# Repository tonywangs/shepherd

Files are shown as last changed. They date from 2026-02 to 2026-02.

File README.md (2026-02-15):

# Shepherd

**An open-source, self-navigating smart white cane for the visually impaired.**

<p align="center">
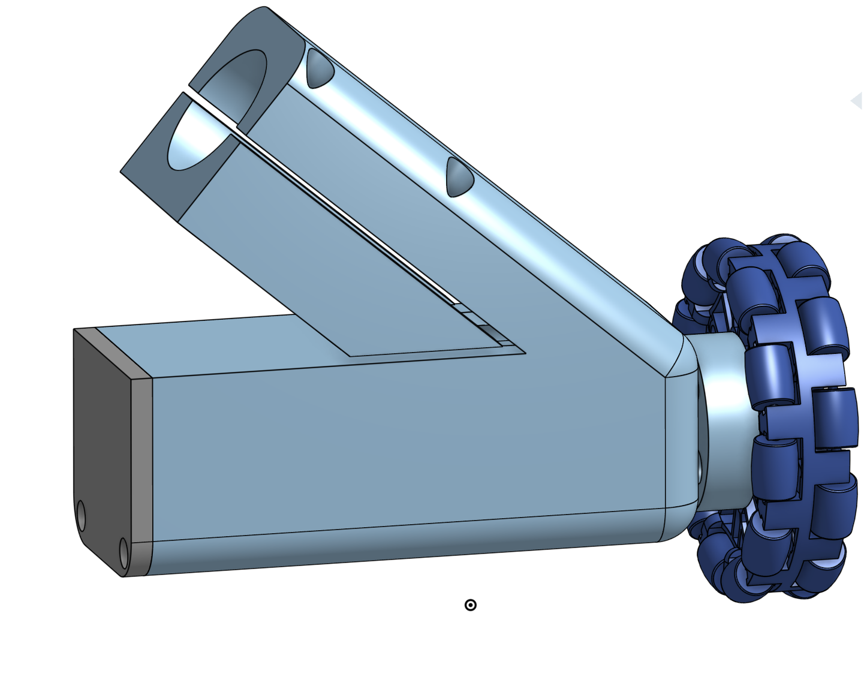
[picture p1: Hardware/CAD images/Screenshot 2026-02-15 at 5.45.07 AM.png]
Shepherd CAD render
  
</p>

> **Demo Video:** *(Coming soon — showing obstacle avoidance, person detection, and GPS navigation in action)*

**Quick Stats:**
- 🚀 **<100ms latency** — 30-50× faster than cloud-based alternatives
- 💰 **~$50 to build** — 1/20th the cost of commercial smart canes
- 🔋 **4-6 hours battery** — charges your phone while you walk
- 🌐 **Fully open-source** — CAD, code, and assembly instructions

---

## Table of Contents

- [The Problem](#the-problem)
- [Our Solution](#our-solution)
- [How It Works](#how-it-works)
  - [Architecture](#architecture)
  - [Sensing & Steering Pipeline](#sensing--steering-pipeline)
  - [Technical Highlights: The Gap-Seeking Algorithm](#technical-highlights-the-gap-seeking-algorithm)
  - [AI Models & Frameworks](#ai-models--frameworks)
- [Hardware](#hardware)
- [Getting Started](#getting-started)
- [Project Structure](#project-structure)
- [Performance Metrics](#performance-metrics)
- [Roadmap](#roadmap)
- [Troubleshooting](#troubleshooting)
- [Contributing](#contributing)
- [Acknowledgments](#acknowledgments)
- [License](#license)

---

## The Problem

Over **253 million people** worldwide live with visual impairments. Many rely on guide dogs, AI glasses, or smart canes to navigate safely — but these tools are prohibitively expensive:

| Tool | Typical Cost |
|---|---|
| Smart canes (e.g. [WeWalk](https://wewalk.io/en/)) | $800 -- $1,150 |
| AI wearables (e.g. OrCam MyEye) | $2,000 -- $5,000 |
| Guide dogs | ~$50,000 (with multi-year waitlists) |

85--90% of people with visual impairments live in developing countries, where any of these costs can eclipse an annual salary. Global access to assistive navigation tools is **under 1%**.

Existing smart canes on the market rely on cloud-based AI (like GPT) for their intelligence — meaning they're subject to cellular connectivity, server latency (4-5 seconds per query), and subscription fees. That latency isn't just inconvenient; when you're approaching a crosswalk or a moving obstacle, it can be the difference between safety and harm.

## Our Solution

Shepherd is a smart cane that **physically guides you** around obstacles using a motorized omni wheel, with all processing done **on-device** on an iPhone. No cloud. No subscriptions. Response time is **under 100ms** — roughly 50x faster than cloud-based alternatives.

It costs a fraction of anything on the market, and we've open-sourced the CAD files, bill of materials, and assembly instructions so **anyone with a 3D printer and a soldering iron can build one**.

### Key Features

- **Physical steering guidance** — a motorized 3.25" omni wheel at the base pushes the cane laterally to steer you around obstacles. You walk forward; Shepherd handles the rest.
- **On-device AI** — LiDAR, camera, and IMU data are processed locally on the iPhone at 30-60 Hz using Apple's Vision framework and ARKit. No internet required for obstacle avoidance.
- **Gap-seeking steering algorithm** — instead of pushing away from obstacles (which causes overcorrection), Shepherd finds the direction of maximum clearance and steers you toward the safest path.
- **Object recognition** — identifies people, surfaces, signs, and obstacles using Apple's Vision framework (`VNDetectHumanRectanglesRequest`, `VNClassifyImageRequest`).
- **GPS navigation** — integrates Google Routes API and OpenRouteService API for turn-by-turn pedestrian routing with infrastructure warnings (crosswalks, traffic signals).
- **Voice assistant** — powered by Vapi, providing conversational guidance with real-time situational awareness of your surroundings.
- **Haptic feedback** — custom-built from recycled e-waste; pulses faster as you approach obstacles, giving you constant spatial awareness.
- **ARKit pose tracking** — 60 Hz heading updates from visual-inertial odometry, fused with compass for drift-resistant orientation.
- **Charges your phone** — a built-in 12V-to-5V step-down powers your iPhone while you walk.

### Prior Work

Shepherd builds on research from Stanford's [Augmented Cane project](https://hai.stanford.edu/news/stanford-researchers-build-400-self-navigating-smart-cane) ([GitHub](https://github.com/pslade2/AugmentedCane)), which demonstrated the viability of omni-wheel steering for assistive navigation. We extend this concept with on-device AI, GPS navigation, object recognition, and a fully open-source hardware design.

---

## How It Works

### Architecture

```
iPhone 14 Pro Max (LiDAR + Camera + IMU + GPS + Compass)
  │
  ├─ ARKit (30-60 Hz)
  │   ├─ LiDAR depth maps (sceneDepth)
  │   ├─ Camera RGB frames
  │   └─ Pose tracking (heading, position)
  │
  ├─ Vision Framework (~2 Hz)
  │   ├─ VNDetectHumanRectanglesRequest (person detection)
  │   └─ VNClassifyImageRequest (scene classification)
  │
  ├─ CoreLocation (1 Hz)
  │   ├─ GPS position
  │   └─ Magnetometer (compass heading)
  │
  ├─ Obstacle Detection & Steering
  │   ├─ Gap profiling (16-column depth analysis)
  │   ├─ Navigation bias (GPS bearing to next waypoint)
  │   └─ Merge: gapCommand + navBias × (1 - proximityFactor)
  │
  └─ BLE (10-20 Hz, custom 12-byte protocol) ──► ESP32-S3
                                                      │
                                              ┌───────┴────────┐
                                              │                │
                                         Motor Control    Haptic Engine
                                       (omni wheel PWM)  (taptic pulses)
                                              │                │
                                        Leaky Integrator   Distance-based
                                        (smooth accel)     (pulse freq)
```

### Sensing & Steering Pipeline

1. **Depth capture** — ARKit captures LiDAR depth maps at 30-60 Hz, along with camera RGB frames for object recognition
2. **Obstacle detection** — depth map is analyzed in left/center/right zones for obstacles, with vertical filtering to ignore ceiling/floor
3. **Person detection** — Vision framework (`VNDetectHumanRectanglesRequest`) runs at ~2 Hz, mapping bounding boxes to LiDAR depth for distance estimation
4. **Gap profiling** — the depth map is split into 16 vertical columns; average depth per column is computed and smoothed with a [0.25, 0.5, 0.25] kernel to find the direction of maximum clearance
5. **Steering computation** — `command = sqrt(|gapDirection|) × proximityFactor`, where `proximityFactor` ramps from 0 (clear) to 1 (obstacle <0.2m). This produces smooth, non-oscillating steering toward the safest path.
6. **Navigation merge (if active)** — GPS navigation bias is blended additively with obstacle avoidance, scaled by `(1 - proximityFactor)` so obstacles always take priority
7. **BLE transmission** — a custom 12-byte protocol sends `{speed, angle, distance, mode}` at 10-20 Hz over Bluetooth Low Energy (write-without-response for minimal latency)
8. **Motor response** — the ESP32 applies a leaky integrator (boat-like momentum model) for smooth acceleration/deceleration, preventing jarring movements
9. **Safety** — if Bluetooth disconnects, the ESP32 auto-decays motor power to zero over ~500ms (no sudden jolts)

### Why On-Device?

As Saqib Shaikh (creator of Microsoft's Seeing AI) has noted, accessibility tech for the visually impaired benefits enormously from edge processing — users can't afford to wait for a cloud round-trip while navigating a crosswalk. Shepherd's core obstacle detection and steering runs entirely on the iPhone with **no network dependency**.

### Technical Highlights: The Gap-Seeking Algorithm

Early prototypes used obstacle repulsion steering (push away from detected obstacles). This failed catastrophically at close range — approaching a trash can dead-center would cause violent oscillation as the system overcorrected left, then right, then left again.

**Our solution:** We replaced repulsive steering with gap-seeking. The algorithm:

1. Profiles the depth map across 16 vertical columns
2. Computes average depth per column (more depth = more clearance)
3. Applies a smoothing kernel to denoise the profile
4. Finds the direction of maximum clearance using argmax
5. Outputs a square-root-boosted command scaled by proximity factor

This eliminates overcorrection by always steering **toward safety** (the clearest path) rather than **away from danger**. Result: smooth, stable navigation even when obstacles are <1 meter away.

### AI Models & Frameworks

| Model/Framework | Purpose | Runs On |
|---|---|---|
| ARKit Visual-Inertial SLAM | LiDAR depth sensing + camera pose tracking | iPhone (60 Hz) |
| `VNDetectHumanRectanglesRequest` | Person detection with bounding boxes | iPhone (Apple Vision) |
| `VNClassifyImageRequest` | Scene/object classification | iPhone (Apple Vision) |
| Vapi Voice Assistant | Conversational AI with real-time sensor context | Cloud (WebRTC) |
| Google Routes API | Pedestrian routing with step-by-step polylines | Cloud |
| OpenRouteService API | Alternative routing + accessibility data | Cloud |

All obstacle detection and steering computation runs **entirely on-device** with zero network dependency. GPS navigation and voice assistant require connectivity but are non-blocking — if offline, obstacle avoidance continues to function.

---

## Hardware

<p align="center">
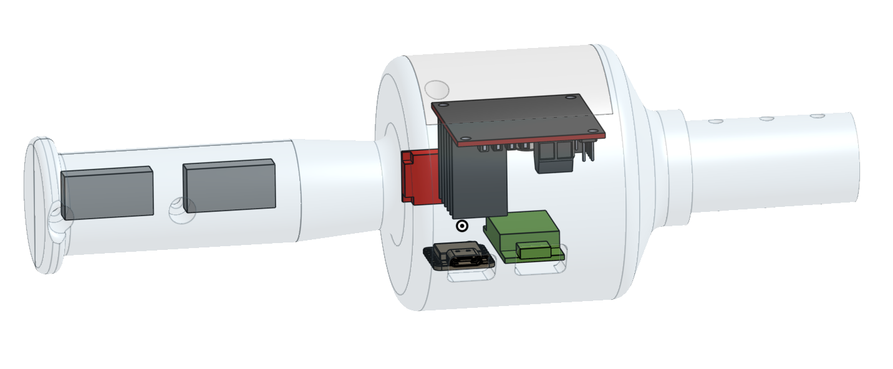
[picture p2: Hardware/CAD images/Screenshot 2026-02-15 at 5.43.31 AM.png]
Shepherd handle CAD
  
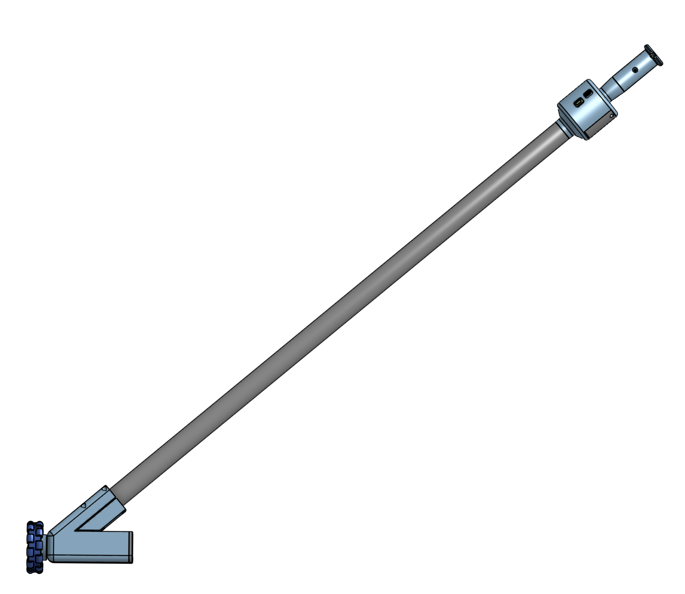
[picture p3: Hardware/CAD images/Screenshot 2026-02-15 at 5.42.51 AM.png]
Shepherd motor mount CAD
  
</p>

The cane is built from 7 custom 3D-printed parts, a GoBilda 5203 Series 312 RPM motor, a 3.25" omni wheel, and a Seeed Studio XIAO ESP32-S3. The handle houses the electronics; the motor assembly clamps to the bottom of a 1.25" PVC pipe.

- **Full BOM and step-by-step assembly instructions:** [`Hardware/Assembly Instructions.md`](Hardware/Assembly%20Instructions.md)
- **CAD files (Onshape):** [View on Onshape](https://cad.onshape.com/documents/81a23f6a3ee770cabe38b40e/w/dbefee79fbdbd29cc2534d7b/e/bc9c36a15806c6943102f855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)
- **STL files for 3D printing:** [`Hardware/`](Hardware/)

---

## Getting Started

### Prerequisites

| Component | Requirement |
|---|---|
| iPhone | 14 Pro Max (or any iPhone with LiDAR), iOS 17.0+ |
| Mac | macOS with Xcode 26.2 installed |
| ESP32 | Seeed Studio XIAO ESP32-S3 |
| Arduino IDE | Version 2.x |
| Hardware | Fully assembled cane (see [Assembly Instructions](Hardware/Assembly%20Instructions.md)) |

### 1. Build the Hardware

Follow the [Hardware Assembly Instructions](Hardware/Assembly%20Instructions.md) to 3D-print, wire, and assemble the cane.

### 2. Flash the ESP32

1. **Install Arduino IDE** (version 2.x)

2. **Add ESP32 board support:**
   - Go to File → Preferences
   - Add this URL to "Additional Boards Manager URLs":
     ```
     https://raw.githubusercontent.com/espressif/arduino-esp32/gh-pages/package_esp32_index.json
     ```
   - Go to Tools → Board → Boards Manager → search and install **esp32**

3. **Select the board:**
   - Tools → Board → ESP32 Arduino → **XIAO_ESP32S3**

4. **Open and upload the firmware:**
   ```bash
   # Open in Arduino IDE:
   ESP32/SmartCane_ESP32/SmartCane_ESP32.ino
   ```
   Click Upload.

5. **Verify it's working:**
   - Open Serial Monitor (115200 baud)
   - You should see: `Smart Cane ESP32-S3 Starting...` and `[BLE] Advertising started`
   - The onboard LED should blink slowly (advertising for a Bluetooth connection)

### 3. Configure API Keys

Create `SmartCane/SmartCane/Secrets.swift` with your API keys:

```swift
import Foundation

struct Secrets {
    static let googleAPIKey = "YOUR_GOOGLE_MAPS_API_KEY"
    static let openRouteServiceAPIKey = "YOUR_OPENROUTE_API_KEY"
    static let vapiPublicKey = "YOUR_VAPI_PUBLIC_KEY"
}
```

**API Key Sources:**
- **Google Maps API**: [Get key from Google Cloud Console](https://console.cloud.google.com/) (enable Geocoding API + Routes API)
- **OpenRouteService**: [Get free key from openrouteservice.org](https://openrouteservice.org/dev/#/signup)
- **Vapi**: [Get key from vapi.ai](https://vapi.ai/) (voice assistant platform)

**Note:** The app will build without these keys, but GPS navigation and voice assistant features will be disabled.

### 4. Build and Run the iOS App

1. **Open the Xcode project:**
   ```bash
   open SmartCane/SmartCane.xcodeproj
   ```

2. **Configure code signing:**
   - Select the SmartCane target
   - Under Signing & Capabilities, choose your development team
   - Update the bundle identifier if needed

3. **Build and run** on your iPhone (must be a physical device with LiDAR — the simulator won't work)

4. **Pair with the cane:**
   - The app will automatically discover the ESP32 over Bluetooth
   - The ESP32 LED will turn solid when connected
   - Press **Start System** in the app

### 5. Test Core Features

**Obstacle Avoidance:**
1. Walk toward a wall — the cane should smoothly steer you away
2. Walk between two obstacles (e.g., chairs) — the cane should find the "gap" and guide you through
3. Approach a person — you should hear "person detected at X meters" from the voice assistant

**Haptic Feedback:**
- As you approach obstacles, the handle should pulse faster
- At <1 meter, pulses should be rapid and intense

**GPS Navigation:**
1. Tap the navigation tab and enter a destination (e.g., "Main Quad, Stanford")
2. Start navigation — you should hear turn-by-turn voice guidance
3. Walk along the route — the cane should blend navigation bias with obstacle avoidance

**Voice Assistant (if configured):**
- Tap "Start Call" to activate Vapi
- Ask "Where am I?" or "Navigate to [destination]"
- The assistant should respond with context-aware guidance

---

## Project Structure

```
├── SmartCane/                      # iOS App (Swift 6.2, Xcode 26.2)
│   └── SmartCane/
│       ├── SmartCaneApp.swift              # App entry point
│       ├── ContentView.swift               # Main UI
│       ├── Core/
│       │   └── SmartCaneController.swift   # Central coordinator
│       ├── Sensors/
│       │   └── DepthSensor.swift           # ARKit + LiDAR depth capture
│       ├── Navigation/
│       │   ├── ObstacleDetector.swift      # Zone-based obstacle analysis
│       │   ├── SteeringEngine.swift        # Lateral steering logic
│       │   ├── SurfaceClassifier.swift     # Terrain classification
│       │   ├── NavigationManager.swift     # GPS route management
│       │   ├── NavigationSteering.swift    # Route-following steering
│       │   └── RouteService.swift          # Routing API integration
│       ├── Vision/
│       │   ├── ObjectRecognizer.swift      # On-device object detection
│       │   └── DepthVisualizer.swift       # Depth map visualization
│       ├── Communication/
│       │   └── ESPBluetoothManager.swift   # BLE (custom 12-byte protocol)
│       ├── Feedback/
│       │   ├── HapticManager.swift         # Distance-based haptic pulses
│       │   └── VoiceManager.swift          # Speech output
│       ├── Voice/
│       │   └── VapiManager.swift           # Voice assistant integration
│       └── Input/
│           └── GameControllerManager.swift # Joy-Con steering override
│
├── ESP32/                          # ESP32 Firmware (Arduino)
│   └── SmartCane_ESP32/
│       └── SmartCane_ESP32.ino             # Motor control + BLE bridge
│
└── Hardware/                       # Hardware Design
    ├── Assembly Instructions.md            # BOM + build guide
    ├── CAD images/                         # Render screenshots
    └── *.stl                               # 3D-printable parts
```

## ESP32 Pin Configuration

```
D0  →  Motor Left Direction
D1  →  Motor Right Direction
D2  →  Motor Enable (PWM speed control)
D3  →  Haptic Motor (Taptic Engine)
LED →  Status indicator (blink = advertising, solid = connected)
```

---

## Performance Metrics

| Metric | Value | Notes |
|---|---|---|
| **Obstacle detection latency** | <33ms | 30-60 Hz depth processing on iPhone |
| **BLE round-trip latency** | <100ms | Write-without-response + leaky integrator on ESP32 |
| **Person detection rate** | ~2 Hz | Throttled to balance accuracy and performance |
| **GPS navigation rate** | ~1 Hz | Standard for CoreLocation pedestrian mode |
| **Total reaction time** | <150ms | From obstacle detection to motor response |
| **Cost to build** | ~$40-60 | Excluding iPhone (BOM details in Hardware/) |
| **Battery life** | ~4-6 hours | Depends on motor usage intensity |

**Comparison:** Cloud-based AI glasses (e.g., Envision) have latency of 4-5 seconds per query. Shepherd's on-device processing is **~30-50× faster**.

---

## Roadmap

**Completed:**
- [x] LiDAR depth sensing + obstacle detection (ARKit, 30-60 Hz)
- [x] Gap-seeking steering algorithm (eliminates overcorrection)
- [x] Ultra-low-latency BLE (custom 12-byte protocol, 10-20 Hz)
- [x] Distance-based haptic feedback (recycled e-waste taptic engine)
- [x] On-device person detection (Vision framework, bounding box + depth)
- [x] On-device scene classification (Vision framework)
- [x] GPS navigation with pedestrian routing (Google Routes + OpenRouteService)
- [x] Voice assistant integration (Vapi, real-time sensor context)
- [x] Navigation-obstacle merge (GPS bias + gap-seeking)
- [x] ARKit pose tracking for heading (60 Hz visual-inertial odometry)
- [x] Joy-Con steering override (for testing/demos)

**In Progress:**
- [ ] Compass-ARKit fusion for drift-resistant heading
- [ ] Waypoint progression with perpendicular projection
- [ ] Sign reading (OCR) and traffic signal detection

**Future Work:**
- [ ] Moving obstacle prediction and trajectory forecasting
- [ ] Indoor positioning (UWB or visual SLAM)
- [ ] Semantic mapping (remember locations and landmarks)
- [ ] Multi-user obstacle sharing (crowd-sourced hazard map)

---

## Troubleshooting

| Problem | Fix |
|---|-----|
| **iPhone can't find ESP32** | Check Serial Monitor shows "Advertising started". Restart Bluetooth on iPhone. Power cycle ESP32. Ensure ESP32 is within 1-2 meters. |
| **BLE connected but motor doesn't move** | Check motor driver power supply (12V) and H-bridge wiring. Open Serial Monitor and verify motor commands are being received. Test motor manually with Arduino digitalWrite. |
| **Motor oscillates or overcorrects** | This was fixed with the gap-seeking algorithm. If still occurring, check that you're running the latest code. Reduce `magnitude` in BluetoothPairingView to 1.5-2.0. |
| **Sluggish steering response** | Move phone closer to ESP32 (<1m). Reduce WiFi/Bluetooth interference. Verify BLE uses write-without-response (not write-with-response). Check that `block_until_ms` is not blocking. |
| **No LiDAR depth data** | Confirm device has LiDAR (iPhone 12 Pro or later). Check ARKit/Camera permissions in Settings. Clean the LiDAR sensor (small black dot near camera). Restart the app. |
| **Weak or no haptic feedback** | Check taptic motor wiring to D3. Verify 5V power supply to motor. Test with different PWM values in Serial Monitor. Try a different taptic motor (recycled from old phones). |
| **Person detection not working** | Verify Vision framework permissions. Check that `processDepthFrame` is being called (watch the console logs). Person detection is throttled to ~2 Hz to save battery. |
| **GPS navigation not starting** | Check that you've added API keys to `Secrets.swift`. Verify Location permissions are granted ("When In Use" or "Always"). Check internet connectivity. |
| **Voice assistant not responding** | Ensure Vapi API key is valid. Check microphone permissions. Verify internet connectivity. Try stopping and restarting the call. |
| **App crashes on launch** | Check that all dependencies are installed (Xcode may need to fetch Swift packages on first build). Clean build folder (Cmd+Shift+K) and rebuild. |

**Full troubleshooting guide:** See [`SETUP_TROUBLESHOOTING.md`](SETUP_TROUBLESHOOTING.md)

---

## Contributing

We welcome contributions! Areas where help is especially appreciated:

- **Hardware improvements** — lighter materials, better phone mounts, waterproofing
- **Algorithm refinement** — moving obstacle prediction, indoor positioning, terrain classification
- **Accessibility testing** — feedback from visually impaired users is invaluable
- **Localization** — translations and region-specific routing data
- **Documentation** — tutorials, videos, improved assembly instructions

**How to contribute:**
1. Fork the repository
2. Create a feature branch (`git checkout -b feature/amazing-feature`)
3. Commit your changes (`git commit -m 'Add amazing feature'`)
4. Push to the branch (`git push origin feature/amazing-feature`)
5. Open a Pull Request

---

## Acknowledgments

- **Stanford Augmented Cane** — [Original research project](https://github.com/pslade2/AugmentedCane) that pioneered omni-wheel steering for white canes
- **Apple** — ARKit and Vision framework make real-time on-device processing possible
- **Vapi** — Voice assistant platform with low-latency real-time context injection
- **TreeHacks 2026** — Stanford's premier hackathon, where Shepherd was built

Special thanks to the visually impaired community members who provided feedback and testing insights during development.

---

## License

MIT License — see [LICENSE](LICENSE) for details.

**Open-source hardware and software.** Build it, modify it, share it.

---

## Contact & Links

- **Project Homepage:** [github.com/yourusername/shepherd](https://github.com/yourusername/shepherd)
- **Demo Video:** *(Coming soon)*
- **CAD Files:** [View on Onshape](https://cad.onshape.com/documents/81a23f6a3ee770cabe38b40e/w/dbefee79fbdbd29cc2534d7b/e/bc9c36a15806c6943102f855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)
- **Devpost:** *(Add TreeHacks submission link)*

**Built at Stanford TreeHacks 2026** 🌲⚡

---

*"Technology should amplify human capability, not amplify cost."*

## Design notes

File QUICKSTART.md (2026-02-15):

# Quick Start Guide

**Get your Smart Cane MVP running in under 1 hour**

## Prerequisites

- Mac with Xcode 26.2 installed
- iPhone 14 Pro Max (or any iPhone with LiDAR)
- Arduino IDE 2.x installed
- Hardware components assembled (see [Hardware/Assembly Instructions.md](Hardware/Assembly%20Instructions.md))

## Part 1: Create iOS Project (15 minutes)

Since Xcode project files are complex, follow these steps to create the project:

### 1. Create New Project

```bash
# Open Xcode
open -a Xcode
```

1. File → New → Project
2. Choose "iOS" → "App"
3. Click "Next"
4. Configure:
   - Product Name: `SmartCane`
   - Team: Your development team
   - Organization Identifier: `com.yourname`
   - Interface: SwiftUI
   - Language: Swift
   - Storage: None
   - Include Tests: No
5. Save to: `/Users/tonywang/raising-canes/SmartCane`

### 2. Add Source Files

Copy all the Swift files from the generated code:

```bash
cd /Users/tonywang/raising-canes/SmartCane/SmartCane

# The following files should already exist:
# - SmartCaneApp.swift
# - ContentView.swift
# - Core/SmartCaneController.swift
# - Sensors/DepthSensor.swift
# - Navigation/ObstacleDetector.swift
# - Navigation/SteeringEngine.swift
# - Communication/BLEManager.swift
# - Feedback/HapticManager.swift
# - Feedback/VoiceManager.swift
```

In Xcode:
1. Right-click "SmartCane" folder in project navigator
2. New Group → Name it "Core"
3. Drag `SmartCaneController.swift` into Core group
4. Repeat for "Sensors", "Navigation", "Communication", "Feedback" groups

### 3. Configure Info.plist

The Info.plist file is already created with all required permissions.

### 4. Add Frameworks

1. Select project in navigator
2. Select "SmartCane" target
3. "Frameworks, Libraries, and Embedded Content"
4. Click "+" and add:
   - ARKit.framework
   - CoreBluetooth.framework
   - AVFoundation.framework
   - Speech.framework
   - CoreHaptics.framework
   - CoreLocation.framework
   - MapKit.framework (for Phase 3)

### 5. Build Settings

1. Select project → SmartCane target
2. Build Settings tab
3. Search for "deployment target"
4. Set iOS Deployment Target to 17.0

### 6. Connect iPhone

1. Connect iPhone 14 Pro Max via USB
2. Trust computer on iPhone
3. In Xcode: Select your iPhone as build target
4. Product → Run (⌘R)

The app should build and launch on your iPhone.

## Part 2: Program ESP32 (10 minutes)

### 1. Install ESP32 Support

1. Open Arduino IDE
2. File → Preferences
3. Additional Board Manager URLs:
   ```
   https://raw.githubusercontent.com/espressif/arduino-esp32/gh-pages/package_esp32_index.json
   ```
4. Tools → Board → Boards Manager
5. Search "esp32"
6. Install "esp32 by Espressif Systems"

### 2. Configure Board

1. Tools → Board → ESP32 Arduino → "XIAO_ESP32S3"
2. Tools → Port → Select your ESP32 port
3. Tools → Upload Speed → "921600"

### 3. Upload Code

1. Open: `/Users/tonywang/raising-canes/ESP32/SmartCane_ESP32/SmartCane_ESP32.ino`
2. Click "Upload" button (→)
3. Wait for "Done uploading"
4. Open Serial Monitor (Tools → Serial Monitor)
5. Set baud rate to 115200
6. You should see:
   ```
   =================================
   Smart Cane ESP32-S3 Starting...
   =================================
   [BLE] Advertising started - waiting for connection...
   ```

## Part 3: Test Connection (5 minutes)

### 1. Power On ESP32

- Disconnect USB
- Connect battery pack
- Power switch ON
- LED should blink slowly

### 2. Launch iPhone App

- Open SmartCane app on iPhone
- You should see:
  - "Disconnected" → "Connected" (turns green)
  - "LiDAR Inactive" status
- Check ESP32 Serial Monitor:
  ```
  [BLE] Client connected
  ```

### 3. Start System

- Tap "Start System" in app
- "LiDAR Active" should turn green
- Point iPhone at a wall
- You should see:
  - Zone indicators change color (red/orange when close)
  - Steering command changes
- Check ESP32 Serial Monitor:
  ```
  [Motor] → LEFT
  [Motor] → NEUTRAL ←
  [Motor] RIGHT →
  ```

## Part 4: Test Motor (10 minutes)

### 1. Bench Test

**WITHOUT attaching to cane:**

1. Place ESP32 + motor assembly on table
2. Secure so it doesn't move
3. Power on
4. In iPhone app: Tap "Start System"
5. Point iPhone at wall on LEFT side
6. Motor should spin (steering RIGHT away from wall)
7. Point iPhone at wall on RIGHT side
8. Motor should spin opposite direction (steering LEFT)

### 2. Check Steering Direction

If motor spins wrong direction:

**Option A (Hardware):**
```
Swap motor wires on L298N:
OUT1 ↔ OUT2
```

**Option B (Software - ESP32 code):**
```cpp
// In SmartCane_ESP32.ino, swap these two:
#define MOTOR_PIN_LEFT  D1  // Was D0
#define MOTOR_PIN_RIGHT D0  // Was D1
```

### 3. Adjust Motor Speed

If motor too weak/strong, edit ESP32 code:

```cpp
#define MOTOR_SPEED_GENTLE   120    // Increase for stronger steering
```

Re-upload to ESP32.

## Part 5: Full System Test (20 minutes)

### 1. Mount to Cane

- Follow [Hardware/Assembly Instructions.md](Hardware/Assembly%20Instructions.md) for mechanical assembly
- Ensure omni wheel contacts ground lightly
- iPhone mounted securely at handle

### 2. Indoor Test

**Test in safe open area first (hallway, large room):**

1. Hold cane at normal walking angle (~60°)
2. iPhone screen visible for monitoring
3. Start system
4. Walk toward wall slowly
5. You should feel lateral pressure on cane handle
6. Cane should gently guide you away from wall

### 3. Fine-Tune Wheel Position

- **Too much force?** Raise motor mount (less ground contact)
- **Too little force?** Lower motor mount (more ground contact)
- **Inconsistent?** Check wheel rotates freely

### 4. Test Scenarios

✅ **Walk toward wall**
- System should steer away
- Haptic pulses increase as you approach
- At ~0.5m, steering becomes aggressive

✅ **Walk through doorway**
- System should steer toward center
- Should avoid both sides

✅ **Obstacle on left**
- System should steer right
- Left zone indicator turns red/orange

✅ **Obstacle on right**
- System should steer left
- Right zone indicator turns red/orange

✅ **Clear path**
- Steering should be neutral
- All zone indicators green
- No lateral force on cane

## Troubleshooting

### App won't build in Xcode

**Error: "Developer Mode disabled"**
- Settings → Privacy & Security → Developer Mode → ON
- Restart iPhone

**Error: "Code signing"**
- Xcode → Project → Signing & Capabilities
- Check "Automatically manage signing"
- Select your team

**Error: "Framework not found"**
- Check all frameworks added (see Part 1, Step 4)

### ESP32 won't upload

**Error: "Port not found"**
- Install CP210x driver (for XIAO ESP32-S3)
- Restart Arduino IDE

**Error: "Upload failed"**
- Hold BOOT button while clicking Upload
- Release after "Connecting..."

### BLE won't connect

**iPhone can't find ESP32:**
- Check ESP32 Serial Monitor shows "Advertising started"
- Settings → Bluetooth → ON
- Force quit and restart SmartCane app
- Power cycle ESP32

**Connects then immediately disconnects:**
- Check battery voltage (should be >6.5V)
- Check ESP32 not crashing (Serial Monitor)

### LiDAR not working

**All zones show "--":**
- Settings → SmartCane → Camera → Allow
- Grant camera permission when prompted
- Clean LiDAR sensor (next to cameras)

**Zones don't update:**
- Check "LiDAR Active" is green
- Walk closer to obstacles (needs <1.5m range)
- Point iPhone forward (not down)

### Motor problems

**Motor doesn't spin:**
1. Check battery connected and charged
2. Verify L298N power LED is ON
3. Check motor connections (no loose wires)
4. Test motor directly with battery

**Motor spins continuously:**
- ESP32 probably not receiving BLE commands
- Check Serial Monitor for command logs
- Verify BLE connected
- Check 500ms timeout working (should auto-stop)

**Motor spins wrong direction:**
- See Part 4, Step 2 (swap wires or pins)

**Motor too weak:**
- Increase `MOTOR_SPEED_GENTLE` in ESP32 code
- Check battery voltage (weak battery = weak motor)
- Verify motor not stalled/blocked

## Performance Benchmarks

After setup, you should see:

| Metric | Target | How to Check |
|---|---|---|
| BLE Latency | <20ms | iPhone app displays latency |
| ARKit Frame Rate | 30-60 fps | Should feel responsive |
| Steering Response | <100ms | Subjective feel while walking |
| Battery Life | 2+ hours | Test runtime |
| Detection Range | 0.3-1.5m | Test with measuring tape |

## Next Steps

Once basic system works:

1. **Tune parameters** (see README.md)
   - Adjust obstacle thresholds
   - Adjust motor speeds
   - Adjust haptic intensity

2. **Implement Phase 2** (object recognition)
   - See PHASE2_GUIDE.md
   - Adds voice announcements

3. **Test in various environments**
   - Different lighting conditions
   - Various obstacle types
   - Indoor vs outdoor

4. **Practice demo**
   - Prepare talking points
   - Have backup cane ready
   - Charge all batteries

## Getting Help

### Serial Monitor Debug Output

**ESP32 (115200 baud):**
```
[BLE] Advertising started
[BLE] Client connected
[Motor] → LEFT / → NEUTRAL ← / RIGHT →
[Haptic] Pulse: 180
```

**Xcode Console (iPhone):**
```
[Controller] Initializing Smart Cane System...
[DepthSensor] ARKit configured for LiDAR at 60fps
[BLE] Scanning for Smart Cane ESP32...
[BLE] Connected to SmartCane
[Controller] Frame processed in 12.34ms
```

### Test Points

**Electrical:**
- Battery voltage: 7.4V ±0.5V
- ESP32 power: 3.3V or 5V
- Motor driver 5V out: ~5V (for powering ESP32)

**Mechanical:**
- Wheel rotates freely (no binding)
- Wheel contacts ground when cane tilted 60°
- Motor has visible torque (can't stop with finger)

## Quick Reference

**BLE UUIDs:**
- Service: `4fafc201-1fb5-459e-8fcc-c5c9c331914b`
- Steering: `beb5483e-36e1-4688-b7f5-ea07361b26a8`
- Haptic: `beb5483e-36e1-4688-b7f5-ea07361b26a9`

**Pin Configuration:**
- D0 → Motor Left
- D1 → Motor Right
- D2 → Motor Enable (PWM)
- D3 → Haptic Motor

**Power Requirements:**
- ESP32: 3.3V / 200mA
- Motor: 6-12V / 1.5A peak
- Battery: 7.4V 2S LiPo recommended

---

**Total Setup Time:** ~1 hour first time, ~15 minutes after
**Difficulty:** Intermediate (hardware + software)
**Success Rate:** High (if hardware assembled correctly)

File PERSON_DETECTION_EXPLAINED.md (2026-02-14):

# Person Detection & Distance Calculation - Technical Explanation

## Overview
The Smart Cane uses a combination of **Vision Framework** (for person detection) and **LiDAR depth sensing** (for distance calculation) to identify and measure the distance to people in the user's path.

---

## How It Works: Step-by-Step

### 1. **Camera Frame Capture** (60fps)
- ARKit captures RGB camera frames at 60fps from iPhone's camera
- Simultaneously captures LiDAR depth map at 60fps
- Both are packaged into `DepthFrame` structure

```swift
struct DepthFrame {
    let depthMap: CVPixelBuffer        // LiDAR depth data
    let capturedImage: CVPixelBuffer?  // RGB camera frame
    let timestamp: TimeInterval
    let cameraTransform: simd_float4x4
}
```

---

### 2. **Person Detection** (Every 5 seconds)
Uses Apple's **Vision Framework** - specifically `VNDetectHumanRectanglesRequest`:

```swift
VNDetectHumanRectanglesRequest { request, error in
    // Returns array of VNHumanObservation with bounding boxes
}
```

**What it detects:**
- Full human bodies in the frame
- Returns normalized bounding box coordinates (0-1 range)
- Works in various poses and lighting conditions
- Hardware-accelerated on A14+ chips (Neural Engine)

**Output:**
```swift
DetectionResult {
    objectName: "person"
    boundingBox: CGRect(x: 0.3, y: 0.4, width: 0.2, height: 0.4)
    // Example: person centered at (0.4, 0.6) in frame
}
```

---

### 3. **Coordinate Conversion**
Convert Vision's normalized coordinates to pixel coordinates in depth map:

**Challenge:** Vision uses **bottom-left** origin, depth map uses **top-left** origin

```swift
// Vision bounding box: (0.5, 0.5) = center of frame
// Must flip Y coordinate for depth map

let centerX = Int(boundingBox.midX * CGFloat(depthMapWidth))
let centerY = Int((1.0 - boundingBox.midY) * CGFloat(depthMapHeight))

// Example:
// boundingBox.midX = 0.5, boundingBox.midY = 0.5
// depthMapWidth = 1920, depthMapHeight = 1440
// → centerX = 960, centerY = 720 (center of depth map)
```

---

### 4. **Depth Sampling Strategy**
Sample multiple depth values around the person's center for robustness:

```swift
// Sample 11×11 grid (121 points) around detected person
for dy in -5...5 {
    for dx in -5...5 {
        let x = centerX + dx
        let y = centerY + dy
        let depth = depthMap[y][x]  // in meters
    }
}
```

**Why multiple samples?**
- LiDAR has noise and occasional invalid readings
- Person might not be perfectly centered in bounding box
- Edges of person might have different depth than center
- Taking median is more robust than single point

**Filtering:**
- Remove invalid values (depth < 0 or depth > 10 meters)
- Remove outliers (background objects)
- Use **median** instead of mean (less affected by outliers)

---

### 5. **Distance Calculation**
```swift
// Example data:
depthValues = [2.31, 2.34, 2.33, 2.35, 2.32, 2.34, ...]
sorted = [2.31, 2.32, 2.33, 2.34, 2.34, 2.35, ...]
median = sorted[60] = 2.34 meters

// Result: Person is 2.34 meters away
```

**Accuracy:**
- ±5cm for distances 0.2m - 5m
- ±10cm for distances 5m - 10m
- Beyond 10m: unreliable (marked as "Clear")

---

## Live Camera View with Overlay

### Real-time Display
1. **Base Camera Feed** (2fps when no detection)
   - Converts CVPixelBuffer → CIImage → CGImage → UIImage
   - Updates every 0.5 seconds for smooth preview
   - Low overhead, doesn't interfere with steering

2. **Detection Overlay** (when person detected)
   - Yellow bounding box drawn on camera frame
   - "Person" label with yellow background
   - Shows exactly where person was detected
   - Updates every 5 seconds with new detections

### Bounding Box Drawing
```swift
// Convert normalized box to pixel coordinates
let rect = CGRect(
    x: boundingBox.minX * imageWidth,
    y: (1.0 - boundingBox.maxY) * imageHeight,  // Flip Y
    width: boundingBox.width * imageWidth,
    height: boundingBox.height * imageHeight
)

// Draw yellow border (4px width)
ctx.setStrokeColor(UIColor.yellow.cgColor)
ctx.setLineWidth(4.0)
ctx.stroke(rect)
```

---

## UI Improvements

### 1. **Distance Display Formatting**
```swift
func formatDistance(_ distance: Float?) -> String {
    guard let dist = distance else { return "--" }

    if dist > 3.0 {
        return "Clear"  // Beyond useful range, prevents UI jumping
    } else {
        return String(format: "%.2fm", dist)
    }
}
```

**Benefits:**
- Consistent width (no UI resizing)
- "Clear" is more intuitive than "10.53m"
- Focuses attention on nearby obstacles

### 2. **Color-Coded Distance Indicators**
- 🔴 **Red**: < 0.5m (Very close - immediate action needed)
- 🟠 **Orange**: 0.5-1.0m (Close - caution required)
- 🟡 **Yellow**: 1.0-2.0m (Moderate - be aware)
- 🟢 **Green**: > 2.0m (Safe - no immediate concern)

### 3. **Visual Progress Bars**
- Proportional bars showing distance
- Longer bar = farther away = safer
- Instant visual feedback without reading numbers

---

## Performance Characteristics

### Frame Processing Pipeline
```
ARKit Frame (60fps)
├─ Depth Map → Obstacle Detection (every frame, ~0.5-2ms)
├─ Depth Map → Depth Visualization (async, optional, ~50ms)
├─ Camera Image → Camera Preview (every 0.5s, ~100ms)
└─ Camera Image → Person Detection (every 5s, ~50-150ms)
    └─ Depth Map → Distance Calculation (~1ms)
```

### Throttling Strategy
- **Obstacle Detection**: Every frame (60fps) - critical for steering
- **Camera Preview**: Every 0.5s (2fps) - smooth enough for visual feedback
- **Person Detection**: Every 5s (0.2fps) - balances accuracy with performance
- **Voice Announcements**: Every 3s cooldown - prevents spam

### Resource Usage
- **CPU**: ~15-20% (mostly Vision framework)
- **GPU**: ~10% (image processing)
- **Memory**: ~150MB additional (Vision models + image buffers)
- **Battery**: ~5-10% additional drain vs Phase 1

---

## Why This Approach Works

### Vision + LiDAR Fusion Benefits
1. **Vision Framework**: Excellent at recognizing *what* something is
2. **LiDAR**: Excellent at measuring *where* something is
3. **Combined**: Get both identity AND distance

### Alternative Approaches (Not Used)
❌ **Depth-only clustering**: Can't distinguish person from wall
❌ **Vision-only depth estimation**: Less accurate than LiDAR
❌ **Single-point depth**: Too noisy, needs multiple samples
✅ **Vision + LiDAR fusion**: Best of both worlds

---

## Example Scenarios

### Scenario 1: Person Walking Toward User
```
t=0s:  Detection: "person" at (0.5, 0.5), Distance: 3.2m → "Clear"
t=5s:  Detection: "person" at (0.5, 0.5), Distance: 2.1m → "2.10m" 🟡
       Voice: "person ahead at 2.1 meters"
t=10s: Detection: "person" at (0.5, 0.5), Distance: 0.8m → "0.80m" 🟠
       Voice: "person ahead at 0.8 meters"
```

### Scenario 2: Person to the Side
```
Detection: "person" at (0.2, 0.5), Distance: 1.5m → "1.50m" 🟡
Bounding box shown on left side of camera view
Steering: Adjusts to avoid left zone
```

---

## Future Enhancements (Not Yet Implemented)

1. **Multiple Person Tracking**
   - Currently detects only closest person
   - Could track up to 3-5 people simultaneously

2. **Distance Prediction**
   - Track person velocity
   - Predict collision time
   - Earlier warnings for fast-moving people

3. **Floor/Curb Detection**
   - Use ARKit plane detection
   - Warn about elevation changes
   - "Curb ahead, step up"

4. **Object Classification**
   - Walls, doors, furniture, cars
   - Different avoidance strategies per object type
   - Currently only detects people

---

## Code References

- **Detection**: `ObjectRecognizer.swift:149-183` (detectPerson method)
- **Distance Calc**: `SmartCaneController.swift:280-338` (calculateDistance method)
- **UI Display**: `ContentView.swift:148-194` (object detection display)
- **Camera Overlay**: `SmartCaneController.swift:276-311` (generateCameraPreview method)

---

## Summary

The Smart Cane's person detection system combines:
- ✅ Real-time person detection (Vision Framework)
- ✅ Accurate distance measurement (LiDAR fusion)
- ✅ Live camera view with bounding boxes
- ✅ Color-coded visual feedback
- ✅ Voice announcements with distance
- ✅ Optimized performance (doesn't block steering)

This multi-modal approach provides users with comprehensive awareness of people in their environment while maintaining the core obstacle avoidance functionality.

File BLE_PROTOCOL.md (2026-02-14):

# BLE Protocol Specification

**Ultra-Low-Latency Communication Protocol for Smart Cane**

## Design Philosophy

This protocol is optimized for minimal latency in a real-time control system. Every design decision prioritizes speed over features.

### Key Optimizations
- **Single-byte packets** - Minimal transmission time
- **Write without response** - No ACK overhead
- **No JSON/serialization** - Direct binary values
- **Persistent connection** - No reconnection overhead
- **High connection priority** - iPhone optimization flags

## Service Definition

### Service UUID
```
4fafc201-1fb5-459e-8fcc-c5c9c331914b
```

This UUID must be identical in both iOS and ESP32 code.

## Characteristics

### 1. Steering Command Characteristic

**UUID:** `beb5483e-36e1-4688-b7f5-ea07361b26a8`

**Direction:** iPhone → ESP32

**Format:** 1 signed byte (int8_t / Int8)

**Values:**
| Value | Meaning | Motor Action |
|---|---|---|
| -1 | LEFT | Omni wheel rolls left (lateral force) |
| 0 | NEUTRAL | Motor stopped (no lateral force) |
| +1 | RIGHT | Omni wheel rolls right (lateral force) |

**Write Mode:** Write Without Response (fastest)

**Update Rate:** ~30 Hz (every 33ms)

**Timeout:** ESP32 stops motor if no command received for 500ms (safety)

#### iOS Implementation
```swift
var command: Int8 = -1  // or 0 or +1
let data = Data(bytes: &command, count: 1)
peripheral.writeValue(data, for: characteristic, type: .withoutResponse)
```

#### ESP32 Implementation
```cpp
void onWrite(BLECharacteristic *pCharacteristic) {
    std::string value = pCharacteristic->getValue();
    if (value.length() == 1) {
        int8_t command = (int8_t)value[0];
        handleSteeringCommand(command);
    }
}
```

### 2. Haptic Trigger Characteristic

**UUID:** `beb5483e-36e1-4688-b7f5-ea07361b26a9`

**Direction:** iPhone → ESP32

**Format:** 1 unsigned byte (uint8_t / UInt8)

**Values:** 0-255 (haptic intensity)
- 0 = No vibration
- 128 = Medium intensity
- 255 = Maximum intensity

**Write Mode:** Write Without Response

**Update Rate:** Variable (triggered by distance changes)

**Purpose:** Trigger vibration motor pulses on ESP32

#### iOS Implementation
```swift
var intensity: UInt8 = 180
let data = Data(bytes: &intensity, count: 1)
peripheral.writeValue(data, for: characteristic, type: .withoutResponse)
```

#### ESP32 Implementation
```cpp
void onWrite(BLECharacteristic *pCharacteristic) {
    std::string value = pCharacteristic->getValue();
    if (value.length() == 1) {
        uint8_t intensity = (uint8_t)value[0];
        analogWrite(HAPTIC_PIN, intensity);
    }
}
```

## Connection Parameters

### iOS Central Configuration
```swift
// Scanning
centralManager.scanForPeripherals(withServices: [serviceUUID], options: nil)

// Connection
centralManager.connect(peripheral, options: nil)

// No connection interval configuration needed - iOS manages automatically
```

### ESP32 Peripheral Configuration
```cpp
// Advertising parameters optimized for iPhone
pAdvertising->setMinPreferred(0x06);  // 7.5ms min interval
pAdvertising->setMaxPreferred(0x12);  // 22.5ms max interval
```

These values optimize for low latency on iOS devices.

## Latency Budget

Target end-to-end latency: **<50ms**

| Component | Target Latency | Notes |
|---|---|---|
| ARKit frame capture | 16-33ms | 30-60 fps |
| Obstacle processing | <5ms | Optimized sampling |
| Steering decision | <1ms | Simple algorithm |
| BLE transmission | <10ms | Write without response |
| ESP32 processing | <1ms | Direct GPIO control |
| **Total** | **<50ms** | Acceptable for steering |

## Error Handling

### Connection Loss
- **iOS:** Automatically restarts scanning
- **ESP32:** Automatically restarts advertising
- **Safety:** Motor stops immediately on disconnect

### Timeout Protection
- **ESP32 side:** If no steering command received for 500ms, motor stops
- **Prevents:** Runaway motor if iPhone crashes or disconnects

### Invalid Commands
- **Handling:** Unknown values default to NEUTRAL (0)
- **Logging:** Errors logged to serial console

## Testing & Validation

### Latency Testing
```swift
// iOS - measure round trip time
let startTime = CFAbsoluteTimeGetCurrent()
peripheral.writeValue(data, for: characteristic, type: .withoutResponse)
let latency = (CFAbsoluteTimeGetCurrent() - startTime) * 1000
print("Latency: \(latency)ms")
```

### Connection Quality
```cpp
// ESP32 - log command reception rate
unsigned long lastCommandTime = 0;
void handleSteeringCommand(int8_t command) {
    unsigned long now = millis();
    unsigned long delta = now - lastCommandTime;
    Serial.printf("Command interval: %lums\n", delta);
    lastCommandTime = now;
}
```

### Expected Performance
- **Command interval:** 30-35ms (30 Hz)
- **Write latency:** <10ms
- **Connection stability:** No drops in 2+ hour session

## Security Considerations

### For Hackathon MVP
- **No encryption:** BLE connection is unencrypted
- **No authentication:** First device found is connected
- **No pairing:** Automatic connection for ease of use

### For Production
Consider adding:
- BLE pairing/bonding
- Encrypted characteristics
- Device whitelisting
- Command validation/checksums

## Debugging Tools

### iOS
```swift
// Enable BLE logging
print("[BLE] State: \(central.state)")
print("[BLE] Peripheral: \(peripheral.name ?? "Unknown")")
print("[BLE] Command sent: \(command)")
```

### ESP32
```cpp
// Serial monitor at 115200 baud
Serial.println("[BLE] Connected");
Serial.printf("[Motor] Command: %d\n", command);
```

### Recommended Debugging Flow
1. Verify ESP32 advertising (serial monitor)
2. Verify iOS scanning (Xcode console)
3. Verify connection (both sides log)
4. Verify characteristic discovery (iOS)
5. Verify command reception (ESP32)
6. Measure latency (iOS)
7. Verify motor response (physical observation)

## Packet Format Summary

Both characteristics use the same simple format:

```
+--------+
| BYTE 0 |  <- Command or intensity value
+--------+
```

**Total packet size:** 1 byte (plus BLE overhead)

**BLE overhead:** ~10 bytes (header, CRC, etc.)

**Total transmission:** ~11 bytes per command

**At 30 Hz:** ~330 bytes/sec = ~2.6 kbps (trivial bandwidth)

## Future Extensions (Phase 2+)

Potential additions without breaking existing protocol:

### Status Feedback (ESP32 → iPhone)
```
UUID: beb5483e-36e1-4688-b7f5-ea07361b26aa
Format: 1 byte bitfield
Bits:
  0: Motor active
  1: Battery low warning
  2: Motor fault
  3-7: Reserved
```

### Extended Commands (Optional)
```
UUID: beb5483e-36e1-4688-b7f5-ea07361b26ab
Format: 2 bytes
Byte 0: Command type
Byte 1: Parameter
```

These are NOT implemented in Phase 1 MVP.

---

**Protocol Version:** 1.0
**Last Updated:** February 2026
**Status:** Stable for Phase 1 MVP

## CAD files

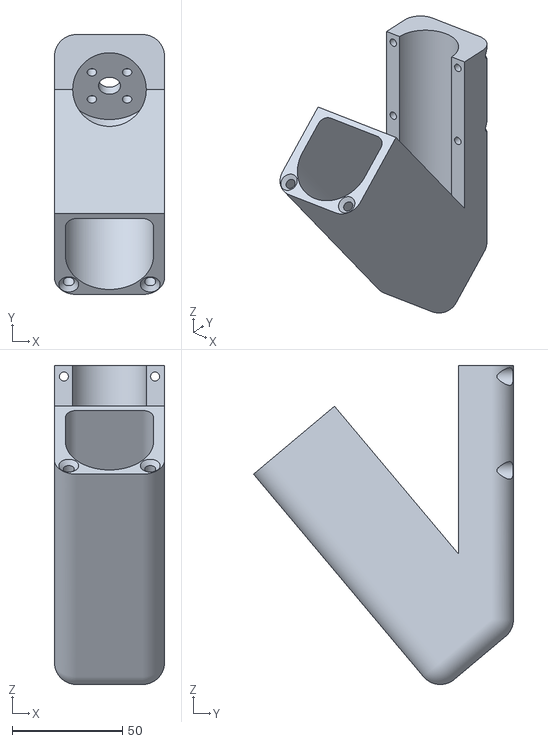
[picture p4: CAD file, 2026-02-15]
Hardware/motor mounting - motor mount (2).stl
50.0 x 118.0 x 144.8

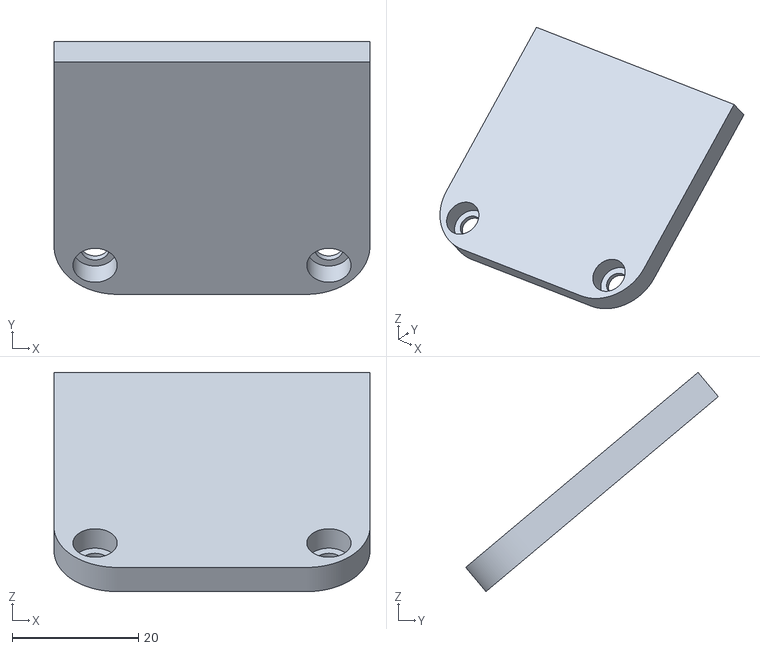
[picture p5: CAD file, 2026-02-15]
Hardware/motor mounting - motor cover (2).stl
50.0 x 40.0 x 34.7

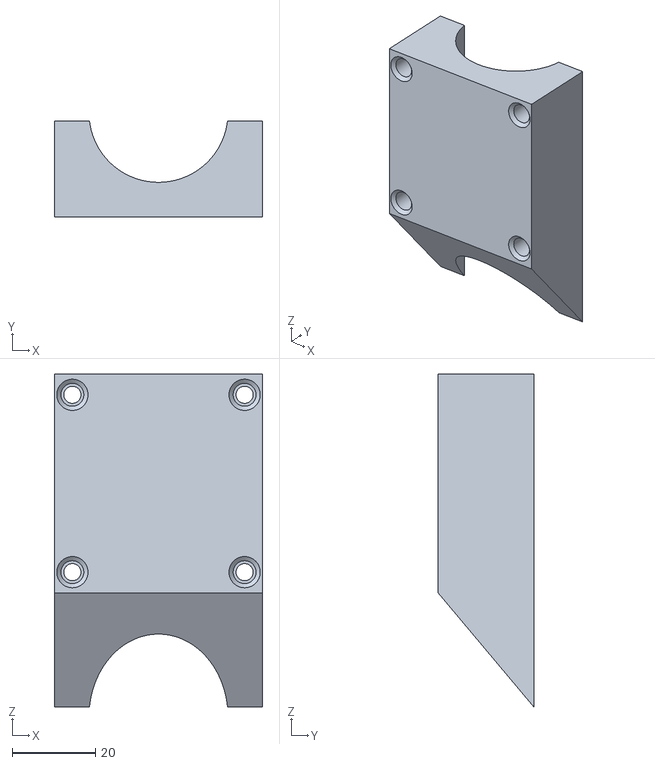
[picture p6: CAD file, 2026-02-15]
Hardware/motor mounting - motor clamp (4).stl
50.0 x 23.0 x 80.0

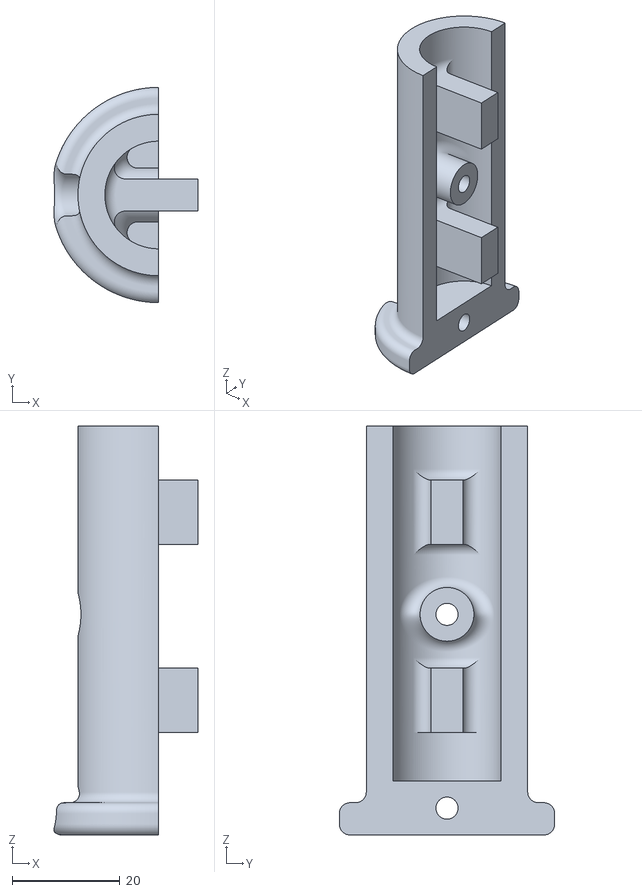
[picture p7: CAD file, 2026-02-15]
Hardware/handle - handle cover (1).stl
26.7 x 40.0 x 76.0

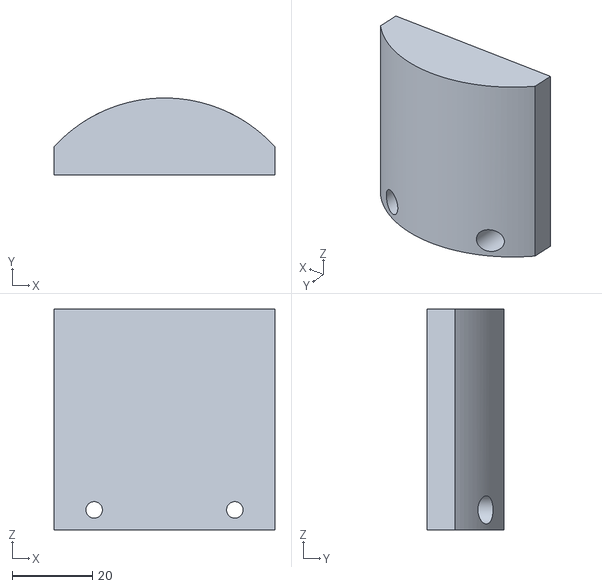
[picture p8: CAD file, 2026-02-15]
Hardware/handle - electronics cover.stl
55.0 x 19.2 x 55.0

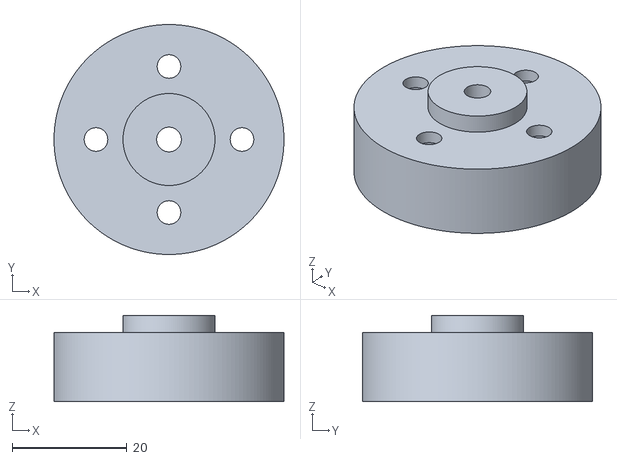
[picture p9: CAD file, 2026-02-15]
Hardware/vex wheel to gobilda hub - wheel adapter.stl
40.0 x 40.0 x 15.0

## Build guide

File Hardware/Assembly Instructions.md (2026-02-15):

# Smart Cane - Hardware Assembly Instructions

> **Estimated build time:** 2-3 hours
>
> **Skill level:** Beginner-Intermediate (basic soldering & 3D printing required)
>
> **CAD file:** [View on Onshape](https://cad.onshape.com/documents/81a23f6a3ee770cabe38b40e/w/dbefee79fbdbd29cc2534d7b/e/bc9c36a15806c6943102f855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)

---

## Bill of Materials (BOM)

### Electronics

| # | Part | Qty | Notes |
|---|---|-----|---|
| 1 | Seeed Studio XIAO ESP32-S3 | 1 | Microcontroller board |
| 2 | L298N Motor Driver | 1 | H-bridge motor controller |
| 3 | GoBilda 5203 Series 312 RPM Motor | 1 | Drive motor for the omni wheel |
| 4 | 3.25" Omni Wheel | 1 | Provides lateral steering force |
| 5 | Apple iPhone 12 Taptic Engine | 1 | Haptic feedback motor (salvaged) |
| 6 | 3S LiPo Battery Cells | 1 set | To build a 3S battery pack |
| 7 | 3S BMS Board | 1 | Battery management system |
| 8 | 12V to 5V Step-Down Converter (with USB output) | 1 | Steps battery voltage down to charge the phone |
| 9 | Phone Charging Cable | 1 | Plugs from the step-down USB into your phone |
| 10 | USB-C Battery Charger Board | 1 | For recharging the battery pack |

### Hardware & Fasteners

| # | Part | Qty | Notes |
|---|---|-----|---|
| 11 | 1.25" PVC Pipe | 1 | Main cane shaft — cut to desired length |
| 12 | M4 Heat-Set Inserts | As needed | Press into 3D-printed parts with soldering iron |
| 13 | M4 Bolts (various lengths) | As needed | For securing motor, clamp, and covers |
| 14 | Heat Shrink Tubing | As needed | To wrap the battery pack |
| 15 | VHB Double-Sided Tape | As needed | To secure charger boards if snap fit is loose |

### 3D-Printed Parts (6 total)

Print all parts from the STL files in this folder. PLA or PETG recommended.

| # | File Name | Qty | Description |
|---|---|-----|---|
| A | `motor mounting - motor mount (2).stl` | 2 | Mounts the motor to the PVC pipe |
| B | `motor mounting - motor cover (2).stl` | 2 | Covers the motor assembly |
| C | `motor mounting - motor clamp (4).stl` | 4 | Clamps the motor in place |
| D | `handle - handle (3).stl` | 3 | Main handle body |
| E | `handle - handle cover (1).stl` | 1 | Covers the top of the handle |
| F | `handle - electronics cover.stl` | 1 | Covers the electronics compartment |
| G | `vex wheel to gobilda hub - wheel adapter.stl` | 1 | Adapts the omni wheel to the GoBilda motor shaft |

---

## Tools You'll Need

- 3D printer (PLA/PETG filament)
- Soldering iron (for heat-set inserts and wiring)
- Allen keys / hex drivers (for M4 bolts)
- Wire strippers / cutters
- Heat gun or lighter (for heat shrink)
- Screwdriver set

---

## Assembly Instructions

### Step 1: Print All Parts

Print each of the 3D-printed parts listed above. Use the quantities shown — some parts need multiple copies. Check your prints against the CAD file to make sure they look right.

### Step 2: Install Heat-Set Inserts

Using your soldering iron, carefully press **M4 heat-set inserts** into all the marked holes on the 3D-printed parts. The holes for inserts are slightly smaller than the insert diameter — the hot iron melts the plastic around the insert as you press it in.

> **Tip:** Go slow and keep the iron straight. Let the insert pull itself in with gravity and heat — don't force it.

### Step 3: Assemble the Motor & Wheel (Bottom of Cane)

1. **Attach the wheel adapter** to the omni wheel using the provided screws.
2. **Mount the adapter + wheel** onto the GoBilda motor shaft.
3. **Screw the motor** into the **motor mount** using M4 bolts.
4. **Feed the motor wire** up through the bottom of the **1.25" PVC pipe**.
5. **Place the motor cover** over the motor.
6. **Loosely attach the motor clamps** around the assembly — don't fully tighten yet (you'll adjust the fit once everything is in the pipe).

### Step 4: Build the Battery Pack

1. Assemble the battery cells into a **3S configuration** (3 cells in series).
2. Wire the cells to the **3S BMS board** following the BMS wiring diagram (it comes with instructions).
3. Wrap the entire battery + BMS assembly in **heat shrink tubing** for protection.

> **Safety note:** Be careful with LiPo cells. Never short the terminals. Always double-check polarity before connecting.

### Step 5: Feed Wires Through the PVC Pipe

1. **Feed the motor wire and battery** into the bottom of the PVC pipe at the same time.
2. **Pull both out the top** of the PVC pipe (the handle end).

> **Tip:** Use a piece of string or a wire fish tape to pull everything through if it's a tight fit.

### Step 6: Wire the Electronics

Connect everything to the **Seeed Studio XIAO ESP32-S3** and the **L298N motor driver**:

| ESP32-S3 Pin | Connects To |
|---|---|
| D0 | L298N — Motor Left Direction |
| D1 | L298N — Motor Right Direction |
| D2 | L298N — Motor Enable (PWM) |
| D3 | Taptic Engine (haptic motor) |

Additional wiring:
- **L298N motor output** → GoBilda motor wires
- **L298N power input** → Battery (via BMS)
- **12V to 5V step-down converter** → Battery 12V output (USB end connects to phone via charging cable)
- **USB-C battery charger board** → Battery (for recharging the battery pack)

> **Tip:** Refer to the ESP32 firmware code (`ESP32/SmartCane_ESP32/SmartCane_ESP32.ino`) if you need to double-check the exact pin assignments.

### Step 7: Assemble the Handle

1. **Place the Taptic Engine** into its designated slot inside the handle.
2. **Place the handle cover** on top of the handle.
3. **Mount the ESP32-S3, L298N, charger boards** into the electronics area of the handle.
   - Use **VHB tape** to secure any boards that don't snap-fit tightly.
4. **Place the electronics cover** on to close up the compartment.

### Step 8: Final Assembly

1. **Connect the battery wire** and **motor wire** coming out of the PVC pipe to the electronics in the handle.
2. **Press the handle assembly onto the top of the PVC pipe.**
3. **Tighten the motor clamps** at the bottom now that everything is in place.
4. **Double-check all connections** before powering on.

---

## You're Done!

To use the Smart Cane:
1. Power on the ESP32 — the LED should blink slowly (advertising via Bluetooth).
2. Open the Smart Cane app on an iPhone with LiDAR.
3. The phone should auto-connect — the ESP32 LED will go solid.
4. Press **Start System** in the app and start walking!

For software setup and troubleshooting, see the main [README.md](../README.md).

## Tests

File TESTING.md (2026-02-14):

# Testing & Validation Guide

**Comprehensive testing procedures for hackathon demo readiness**

## Test Strategy

The Smart Cane system has multiple subsystems that must work together. Test each subsystem independently before integration testing.

## Phase 1: Unit Tests

### 1.1 ESP32 Hardware Test

**Objective:** Verify ESP32 + motor driver + motor chain works

**Setup:**
- ESP32 powered via USB (no battery yet)
- Motor driver connected
- Motor connected
- Serial monitor open

**Test Steps:**

```cpp
// Add to setup() in ESP32 code temporarily:
void testMotor() {
    Serial.println("=== MOTOR TEST ===");

    Serial.println("Test 1: Motor LEFT");
    steerLeft(150);
    delay(2000);
    stopMotor();
    delay(1000);

    Serial.println("Test 2: Motor RIGHT");
    steerRight(150);
    delay(2000);
    stopMotor();
    delay(1000);

    Serial.println("Test 3: Speed ramp");
    for (int speed = 0; speed <= 255; speed += 25) {
        steerRight(speed);
        Serial.printf("Speed: %d\n", speed);
        delay(500);
    }
    stopMotor();

    Serial.println("=== TEST COMPLETE ===");
}
```

**Expected Results:**
- Motor spins left for 2 seconds
- Motor spins right for 2 seconds
- Motor speed increases gradually
- No burning smell, no overheating

**Pass Criteria:**
- ✅ Motor responds to all commands
- ✅ Direction changes correctly
- ✅ Speed control works
- ✅ No electrical issues

---

### 1.2 ESP32 BLE Test

**Objective:** Verify BLE advertising and connection

**Setup:**
- ESP32 powered on
- Serial monitor open
- iPhone Bluetooth ON
- Use LightBlue app (free iOS BLE scanner)

**Test Steps:**
1. Power on ESP32
2. Open LightBlue app on iPhone
3. Look for "SmartCane" in device list
4. Connect to SmartCane
5. View services
6. Find service `4fafc201-...`
7. Find characteristic `beb5483e-...-26a8` (steering)
8. Write hex value `01` (steer right)
9. Check serial monitor

**Expected Results:**
```
[BLE] Advertising started
[BLE] Client connected
[Motor] RIGHT →
```

**Pass Criteria:**
- ✅ Device shows up in LightBlue
- ✅ Can connect successfully
- ✅ Service and characteristics visible
- ✅ Writing to characteristic triggers motor
- ✅ Serial monitor logs commands

---

### 1.3 iPhone ARKit Test

**Objective:** Verify LiDAR depth sensing works

**Setup:**
- iPhone app built and running
- Camera permissions granted

**Test Method:**

Add temporary debug view to ContentView.swift:

```swift
// Add to ContentView body:
if let depthFrame = caneController.depthSensor?.latestDepthFrame {
    Text("Depth data active: \(depthFrame.timestamp)")
        .font(.caption)
}
```

**Test Steps:**
1. Launch app
2. Point at wall 1 meter away
3. Observe center distance reading
4. Move closer (0.5m)
5. Move farther (2m)
6. Point at different objects

**Expected Results:**
- Center distance shows ~1.0m
- Distance decreases when moving closer
- Distance increases when moving farther
- Updates in real-time (30-60 fps)

**Pass Criteria:**
- ✅ Depth values reasonable (0.3-1.5m range)
- ✅ Updates continuously
- ✅ Responds to movement
- ✅ No app crashes

---

### 1.4 iPhone Obstacle Detection Test

**Objective:** Verify zone-based obstacle detection

**Test Method:**

Add debug logging to ObstacleDetector.swift:

```swift
let zones = ObstacleZones(...)

print("[Zones] L:\(zones.leftDistance ?? -1) C:\(zones.centerDistance ?? -1) R:\(zones.rightDistance ?? -1)")

return zones
```

**Test Steps:**
1. Launch app, start system
2. Point at wall straight ahead
3. Check logs: center should have distance
4. Point at wall on left side
5. Check logs: left should have distance
6. Point at open space
7. Check logs: all should be nil or >1.5m

**Expected Results:**
```
[Zones] L:-1 C:0.8 R:-1       // Wall ahead
[Zones] L:0.5 C:-1 R:-1       // Wall on left
[Zones] L:-1 C:-1 R:-1        // Clear path
```

**Pass Criteria:**
- ✅ Zones correctly identify obstacle position
- ✅ Distance values accurate
- ✅ Clear paths show no obstacles

---

### 1.5 Steering Logic Test

**Objective:** Verify steering decisions make sense

**Test Method:**

Add to SteeringEngine.swift:

```swift
let decision = SteeringDecision(...)

print("[Steering] Command:\(decision.command) Reason:\(decision.reason)")

return decision
```

**Test Scenarios:**

| Scenario | L | C | R | Expected Command | Expected Reason |
|---|---|---|---|---|---|
| Wall ahead | - | 0.8 | - | -1 or +1 | Avoid center |
| Wall on left | 0.5 | - | - | +1 | Avoid left |
| Wall on right | - | - | 0.5 | -1 | Avoid right |
| Clear path | - | - | - | 0 | Clear path |
| Narrow gap | 1.0 | - | 1.2 | +1 | Prefer right (more space) |

**Pass Criteria:**
- ✅ All scenarios produce correct commands
- ✅ Reasons make sense
- ✅ Confidence values reasonable

---

## Phase 2: Integration Tests

### 2.1 End-to-End Latency Test

**Objective:** Measure total system latency

**Test Method:**

1. Add timestamp logging to pipeline
2. Measure from ARFrame → Motor command

```swift
// In SmartCaneController.swift:
let t0 = CFAbsoluteTimeGetCurrent()

// ... processing ...

let latency = (CFAbsoluteTimeGetCurrent() - t0) * 1000
print("[Latency] Total: \(latency)ms")
```

**Test Steps:**
1. Start system
2. Walk around for 30 seconds
3. Calculate average latency from logs
4. Check max latency

**Expected Results:**
- Average: 20-40ms
- Max: <80ms
- 95th percentile: <50ms

**Pass Criteria:**
- ✅ Average latency <50ms
- ✅ No latency spikes >100ms
- ✅ Feels responsive when walking

---

### 2.2 BLE Reliability Test

**Objective:** Verify stable BLE connection

**Test Method:**

```swift
// Track connection stats in BLEManager:
var totalPacketsSent = 0
var connectionDrops = 0
var lastConnectionTime: Date?

func sendSteeringCommand(_ command: Int8) {
    totalPacketsSent += 1
    // ... existing code ...
}
```

**Test Steps:**
1. Connect BLE
2. Run system for 5 minutes
3. Monitor serial output for disconnects
4. Count total packets sent

**Expected Results:**
- Packets sent: ~9000 (30 Hz × 300 seconds)
- Connection drops: 0
- No reconnection needed

**Pass Criteria:**
- ✅ Zero disconnections in 5 minute test
- ✅ Packet rate consistent (~30 Hz)
- ✅ No command loss (verified in serial logs)

---

### 2.3 Steering Response Test

**Objective:** Verify motor responds correctly to obstacles

**Test Setup:**
- Cane mounted with all hardware
- Phone secured to handle
- Motor can spin freely (not touching ground yet)

**Test Steps:**

| Action | Expected Motor Response | Verify in Serial |
|---|---|---|
| Point at wall ahead | LEFT or RIGHT (whichever has more space) | `[Motor] ← LEFT` or `RIGHT →` |
| Point at open space | NEUTRAL | `[Motor] → NEUTRAL ←` |
| Point at wall on left | RIGHT | `[Motor] RIGHT →` |
| Point at wall on right | LEFT | `[Motor] ← LEFT` |
| Block center zone | Steer to clearer side | Command changes to open side |

**Pass Criteria:**
- ✅ Motor direction matches steering logic
- ✅ Response time <100ms (subjective)
- ✅ Serial logs match expected commands

---

### 2.4 Haptic Feedback Test

**Objective:** Verify haptic pulses match distance

**Test Method:**

Add logging to HapticManager:

```swift
func updateDistance(_ distance: Float) {
    print("[Haptic] Distance:\(distance) Interval:\(interval)")
    // ... existing code ...
}
```

**Test Steps:**
1. Start system
2. Walk toward wall slowly
3. Note haptic pulse rate at different distances
4. Should feel:
   - 1.5m: Slow pulse (~1 Hz)
   - 1.0m: Medium pulse (~3 Hz)
   - 0.5m: Fast pulse (~7 Hz)
   - 0.3m: Very fast pulse (~10 Hz)

**Pass Criteria:**
- ✅ Pulse rate increases as distance decreases
- ✅ Pulses stop when >1.5m away
- ✅ Pulses feel distinct (not continuous vibration)

---

## Phase 3: System Tests

### 3.1 Basic Navigation Test

**Objective:** Verify lateral steering works while walking

**Test Environment:** Indoor hallway with clear walls

**Test Steps:**
1. Stand at one end of hallway (center)
2. Start system
3. Walk forward slowly
4. Cane should remain centered
5. Drift slightly left
6. Cane should push back to center
7. Drift slightly right
8. Cane should push back to center

**Pass Criteria:**
- ✅ Cane provides lateral force when needed
- ✅ Force is gentle, not aggressive
- ✅ User can override force if desired
- ✅ Cane returns to neutral in open space

---

### 3.2 Obstacle Avoidance Test

**Test Scenarios:**

**A. Wall Approach**
1. Walk directly toward wall from 2m away
2. At ~1.2m, should feel steering force
3. At ~0.6m, force should increase
4. Stop at ~0.3m (or before collision)

**Pass Criteria:**
- ✅ Steering engages before collision
- ✅ Direction is away from wall
- ✅ Force proportional to distance

---

**B. Narrow Doorway**
1. Walk toward doorway (off-center)
2. Cane should guide toward center
3. Should thread through doorway
4. Steering disengages once through

**Pass Criteria:**
- ✅ Avoids both sides of doorway
- ✅ Finds center path
- ✅ Smooth transition

---

**C. Corner Navigation**
1. Walk along wall (wall on left)
2. Approach corner (ahead + left blocked)
3. Cane should steer right
4. Walk around corner

**Pass Criteria:**
- ✅ Detects corner as center + side obstacle
- ✅ Steers toward open side
- ✅ Allows user to turn

---

### 3.3 Multi-Obstacle Test

**Test Environment:** Room with chairs, tables, etc.

**Test Steps:**
1. Walk through cluttered environment
2. System should avoid multiple obstacles
3. Should not get "stuck" between obstacles

**Pass Criteria:**
- ✅ Detects various obstacle types
- ✅ Provides coherent steering guidance
- ✅ Doesn't oscillate between left/right
- ✅ User can make progress through space

---

### 3.4 Battery Endurance Test

**Objective:** Verify 2+ hour runtime

**Test Method:**
1. Fully charge battery
2. Power on system
3. Run continuously (walking or bench test)
4. Monitor battery voltage every 15 minutes
5. Record time until system fails

**Expected Results:**
- 7.4V LiPo 2500mAh: 2-3 hours
- Voltage drop: 8.4V → 6.0V (cutoff)

**Pass Criteria:**
- ✅ Minimum 2 hours runtime
- ✅ No brownouts or resets
- ✅ Motor maintains performance until battery depleted

---

## Phase 4: Environmental Tests

### 4.1 Lighting Conditions

Test in various lighting:

| Condition | LiDAR Expected | Notes |
|---|---|---|
| Bright indoor | ✅ Works | Optimal |
| Dim indoor | ✅ Works | LiDAR not affected by light |
| Dark indoor | ✅ Works | LiDAR active sensing |
| Bright sunlight | ⚠️ May degrade | IR interference possible |
| Direct sunlight | ⚠️ May degrade | Test fallback behavior |

**Pass Criteria:**
- ✅ Works in all indoor conditions
- ⚠️ Acceptable degradation outdoors (hackathon MVP ok)

---

### 4.2 Surface Types

Test obstacle detection on:

| Surface | Detection Expected | Notes |
|---|---|---|
| White wall | ✅ Excellent | High IR reflectance |
| Dark wall | ✅ Good | Some absorption |
| Glass window | ⚠️ Variable | May see through |
| Mirror | ❌ Poor | Specular reflection |
| Curtain | ⚠️ Variable | Soft material |

**Pass Criteria:**
- ✅ Reliably detects walls/doors
- ⚠️ Glass/mirrors acceptable limitation for MVP

---

### 4.3 Range Test

**Test Method:**

1. Position phone at exact distances from wall
2. Record detected distance
3. Calculate error

| Actual Distance | Measured Distance | Error |
|---|---|---|
| 0.3m | ? | ? |
| 0.5m | ? | ? |
| 1.0m | ? | ? |
| 1.5m | ? | ? |
| 2.0m | ? | ? |

**Pass Criteria:**
- ✅ Error <10% for distances 0.3-1.5m
- ⚠️ Acceptable error >1.5m (out of range)

---

## Phase 5: Demo Rehearsal

### 5.1 Demo Run-Through

**Objective:** Practice full demo script

**Setup:**
- Fully assembled system
- Batteries charged
- Test environment prepared
- Backup components ready

**Demo Script:**
1. **Introduction** (30 seconds)
   - Show system components
   - Explain lateral steering concept

2. **Connection Demo** (30 seconds)
   - Power on ESP32
   - Launch iPhone app
   - Show connection established

3. **Basic Avoidance** (1 minute)
   - Walk toward wall
   - Show steering engages
   - Show haptic feedback

4. **Doorway Navigation** (1 minute)
   - Walk through doorway
   - Show centering behavior

5. **UI Demo** (30 seconds)
   - Show live zone indicators
   - Show steering commands
   - Show latency metrics

6. **(Optional) Phase 2** (30 seconds)
   - Object recognition announcement

**Total Demo Time:** 3-4 minutes

**Pass Criteria:**
- ✅ No technical failures
- ✅ Clear demonstration of value
- ✅ All features work

---

### 5.2 Failure Mode Testing

**Objective:** Identify and prepare for potential demo failures

**Test Scenarios:**

**A. BLE Disconnects Mid-Demo**
- **Cause:** Interference, battery, range
- **Recovery:** Auto-reconnect (already implemented)
- **Backup:** Have spare ESP32 powered on

**B. iPhone App Crashes**
- **Cause:** Memory, ARKit failure
- **Recovery:** Force quit and restart (15 seconds)
- **Backup:** Have app pre-loaded on backup iPhone

**C. Motor Stops Working**
- **Cause:** Battery dead, driver failure, loose wire
- **Recovery:** Can't fix quickly
- **Backup:** Have backup cane fully assembled

**D. LiDAR Stops Working**
- **Cause:** App issue, permissions, ARKit crash
- **Recovery:** Restart app
- **Backup:** Have backup iPhone

**E. Battery Dies**
- **Cause:** Forgot to charge
- **Backup:** Have 2-3 charged batteries, labeled

**Pass Criteria:**
- ✅ Identified recovery for each failure
- ✅ Backup hardware available
- ✅ Can recover within 1 minute

---

## Testing Checklist

Before demo day:

### Day Before Demo
- [ ] Full battery endurance test (2+ hours)
- [ ] All unit tests passing
- [ ] Integration tests passing
- [ ] Demo rehearsal 3x with team
- [ ] Backup hardware tested and ready
- [ ] All batteries charged

### Demo Day Morning
- [ ] Charge all batteries to 100%
- [ ] Test primary system (full run-through)
- [ ] Test backup system (full run-through)
- [ ] Pack backup hardware
- [ ] Pack tools (screwdrivers, tape, zip ties)
- [ ] Label all components

### Pre-Demo (30 min before)
- [ ] Fresh battery in primary system
- [ ] Test BLE connection
- [ ] Test LiDAR
- [ ] Test motor
- [ ] Backup system powered and ready
- [ ] iPhone app pre-loaded (not suspended)

---

## Performance Metrics Summary

**Target Metrics (MVP):**

| Metric | Target | Stretch Goal |
|---|---|---|
| End-to-end latency | <50ms | <30ms |
| BLE latency | <20ms | <10ms |
| ARKit frame rate | 30 fps | 60 fps |
| Detection range | 0.3-1.5m | 0.2-2.0m |
| Detection accuracy | >90% | >95% |
| BLE reliability | 0 drops/5min | 0 drops/hour |
| Battery life | 2 hours | 4 hours |
| Steering response | <100ms | <50ms |

---

**Test Status:** Complete all Phase 1-3 tests before demo
**Last Updated:** February 2026
**Estimated Testing Time:** 4-6 hours total

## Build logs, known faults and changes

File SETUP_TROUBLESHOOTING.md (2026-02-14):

# Smart Cane iOS App - Setup & Troubleshooting Guide

**Complete walkthrough of Xcode project setup and all errors encountered**

---

## Table of Contents
1. [Initial Problem: Project Won't Open](#initial-problem-project-wont-open)
2. [Creating Xcode Project from Scratch](#creating-xcode-project-from-scratch)
3. [Build Errors & Fixes](#build-errors--fixes)
4. [Runtime Crashes & Fixes](#runtime-crashes--fixes)
5. [Final Working Configuration](#final-working-configuration)

---

## Initial Problem: Project Won't Open

### Error
```
Failed to load project at '/Users/shanemion/TreeHacks2026/raising-canes/SmartCane/SmartCane.xcodeproj'
for an unknown reason.
```

### Root Cause
The repository contained Swift source files but had an empty/stub `project.pbxproj` file (only 173 bytes). The Xcode project structure existed but wasn't functional.

**Investigation:**
```bash
ls -la SmartCane/SmartCane.xcodeproj/
# Output: project.pbxproj was only 173 bytes (should be several KB)

cat SmartCane/SmartCane.xcodeproj/project.pbxproj
# Output: Just a stub with no real project structure
```

### Solution
Create a new Xcode project from scratch and add the existing source files.

---

## Creating Xcode Project from Scratch

### Step 1: Rename Existing Folder
```bash
cd /Users/shanemion/TreeHacks2026/raising-canes
mv SmartCane SmartCane_Source
```

**Why:** Prevent file conflict when Xcode creates the new project folder.

---

### Step 2: Create New Xcode Project

1. Open Xcode
2. **File → New → Project**
3. Choose **iOS → App**
4. Configure:
   - **Product Name:** SmartCane
   - **Team:** Your development team
   - **Organization Identifier:** com.yourname
   - **Interface:** SwiftUI
   - **Language:** Swift
   - **Storage:** None
   - **Include Tests:** Uncheck both boxes
5. **Save to:** `/Users/shanemion/TreeHacks2026/raising-canes/`

---

### Step 3: Add Source Files to Project

1. Delete auto-generated files:
   - Right-click `ContentView.swift` → Delete → Move to Trash
   - Right-click `SmartCaneApp.swift` → Delete → Move to Trash

2. Add existing source files:
   - Right-click "SmartCane" folder in Project Navigator
   - **Add Files to "SmartCane"...**
   - Navigate to `/Users/shanemion/TreeHacks2026/raising-canes/SmartCane_Source/SmartCane/`
   - Select **ALL** Swift files and folders
   - **Important options:**
     - ✅ **Copy items if needed**
     - ✅ **Create groups** (not folder references)
     - ✅ **Add to targets: SmartCane**
   - Click **Add**

---

### Step 4: Add Required Frameworks

1. Select **SmartCane project** in navigator
2. Select **SmartCane target**
3. Go to **"Frameworks, Libraries, and Embedded Content"** tab
4. Click **"+"** and add:
   - `ARKit.framework`
   - `CoreBluetooth.framework`
   - `AVFoundation.framework`
   - `Speech.framework`
   - `CoreHaptics.framework`
   - `CoreLocation.framework`
   - `MapKit.framework`

---

### Step 5: Configure Build Settings

1. Select project → SmartCane target
2. **Build Settings** tab
3. Search for **"deployment"**
4. Set **iOS Deployment Target** to **17.0**

---

## Build Errors & Fixes

### Error 1: Multiple Info.plist Conflict

**Error Message:**
```
Multiple commands produce '/Users/shanemion/Library/Developer/Xcode/DerivedData/SmartCane-.../Info.plist'
```

**Root Cause:**
- Info.plist file was included in source files
- Xcode also tries to auto-generate Info.plist
- Both try to copy to the same location → conflict

**Fix:**
1. Select SmartCane target
2. Go to **Build Phases** tab
3. Expand **"Copy Bundle Resources"**
4. Find `Info.plist` in the list
5. Select it and click **"-"** (minus) button to remove

Modern Xcode projects don't need a separate Info.plist file.

---

### Error 2: Missing `import Combine`

**Error Messages:**
```
HapticManager.swift:12:7 Type 'HapticManager' does not conform to protocol 'ObservableObject'
VoiceManager.swift:12:7 Type 'VoiceManager' does not conform to protocol 'ObservableObject'
VoiceManager.swift:19:6 Initializer 'init(wrappedValue:)' is not available due to missing import of defining module 'Combine'
ObjectRecognizer.swift:14:7 Type 'ObjectRecognizer' does not conform to protocol 'ObservableObject'
```

**Root Cause:**
Files using `@Published` and `ObservableObject` need to import the Combine framework.

**Fix:**
Add `import Combine` to these files:

**HapticManager.swift:**
```swift
import Foundation
import CoreHaptics
import Combine  // ← ADD THIS
```

**VoiceManager.swift:**
```swift
import Foundation
import AVFoundation
import Speech
import Combine  // ← ADD THIS
```

**ObjectRecognizer.swift:**
```swift
import Foundation
import Vision
import CoreImage
import AVFoundation
import Combine  // ← ADD THIS
```

---

## Runtime Crashes & Fixes

### Error 3: Privacy Permissions Crash

**Error Message:**
```
This app has crashed because it attempted to access privacy-sensitive data without a usage description.
The app's Info.plist must contain an NSSpeechRecognitionUsageDescription key with a string value
explaining to the user how the app uses this data.
```

**Root Cause:**
iOS requires explicit permission descriptions for accessing:
- Camera (for LiDAR)
- Bluetooth (for ESP32 communication)
- Microphone (for voice input)
- Speech Recognition (for voice commands)

**Fix:**
Add privacy keys to the project:

1. Select **SmartCane target**
2. Go to **"Info"** tab
3. Find **"Custom iOS Target Properties"**
4. Right-click on any existing row → **"Add Row"**
5. Add these keys (one at a time):

| Key | Value |
|-----|---|
| `Privacy - Camera Usage Description` | `We need camera access for LiDAR depth sensing to detect obstacles.` |
| `Privacy - Bluetooth Always Usage Description` | `We need Bluetooth to communicate with the Smart Cane motor controller.` |
| `Privacy - Microphone Usage Description` | `We need microphone access for voice commands.` |
| `Privacy - Speech Recognition Usage Description` | `We need speech recognition for voice control features.` |
| `Privacy - Location When In Use Usage Description` | `We need location access for GPS navigation guidance.` |

**Alternative:** Use raw key names if auto-complete doesn't work:
- `NSCameraUsageDescription`
- `NSBluetoothAlwaysUsageDescription`
- `NSMicrophoneUsageDescription`
- `NSSpeechRecognitionUsageDescription`
- `NSLocationWhenInUseUsageDescription`

---

### Error 4: Black Screen - VoiceManager Initialization Crash

**Symptoms:**
- App builds successfully
- App launches but shows black/blank screen
- No UI renders at all
- Console shows initialization stops after HapticManager

**Console Output:**
```
[ContentView] View appeared, initializing controller...
[Controller] Initializing Smart Cane System...
[Controller] Core systems initialized
(Fig) signalled err=-12710 at <>:601
[DepthSensor] ARKit configured for LiDAR at 60fps
[Controller] DepthSensor initialized
[Controller] BLEManager initialized
[Controller] HapticManager initialized
← STOPS HERE, never reaches VoiceManager
```

**Root Cause:**
`VoiceManager` initialization was crashing silently, preventing the entire app from rendering.

**Diagnostic Process:**

1. **Test with minimal UI** - Created ultra-simple ContentView with no controller:
```swift
struct ContentView: View {
    var body: some View {
        Color.red.ignoresSafeArea()  // Just a red screen
        Text("Test")
    }
}
```
Result: Red screen showed → UI rendering works, controller is the problem.

2. **Progressive initialization** - Added logging to each subsystem initialization:
```swift
func initialize() {
    obstacleDetector = ObstacleDetector()
    print("[Controller] ObstacleDetector initialized")  // ✓

    steeringEngine = SteeringEngine()
    print("[Controller] SteeringEngine initialized")    // ✓

    depthSensor = DepthSensor()
    print("[Controller] DepthSensor initialized")       // ✓

    bleManager = BLEManager()
    print("[Controller] BLEManager initialized")        // ✓

    hapticManager = HapticManager()
    print("[Controller] HapticManager initialized")     // ✓

    voiceManager = VoiceManager()
    print("[Controller] VoiceManager initialized")      // ✗ NEVER PRINTED
}
```

3. **Identified culprit** - VoiceManager was crashing during initialization.

**Fix:**
Temporarily disable VoiceManager initialization:

**SmartCaneController.swift:**
```swift
func initialize() {
    print("[Controller] Initializing Smart Cane System...")

    // Initialize simple subsystems first (no hardware dependencies)
    obstacleDetector = ObstacleDetector()
    steeringEngine = SteeringEngine()
    print("[Controller] Core systems initialized")

    // Initialize hardware subsystems
    depthSensor = DepthSensor()
    print("[Controller] DepthSensor initialized")

    bleManager = BLEManager()
    print("[Controller] BLEManager initialized")

    hapticManager = HapticManager()
    print("[Controller] HapticManager initialized")

    // TEMPORARY: VoiceManager disabled due to initialization crash
    // voiceManager = VoiceManager()
    print("[Controller] VoiceManager SKIPPED (temporarily disabled)")

    setupDataPipeline()
    print("[Controller] System initialized. Ready to start.")
}
```

Update methods that use VoiceManager:
```swift
private func startSystem() {
    depthSensor?.start()
    isARRunning = true
    bleManager?.startScanning()
    hapticManager?.initialize()

    // Safe voice announcement
    if voiceManager != nil {
        voiceManager?.speak("Smart cane activated")
    } else {
        print("[Controller] Voice announcement skipped (VoiceManager disabled)")
    }
}

func testVoice() {
    if voiceManager != nil {
        voiceManager?.speak("Voice system working correctly")
    } else {
        print("[Controller] Voice test skipped (VoiceManager disabled)")
    }
}
```

---

## Final Working Configuration

### Working Features ✅
- ✅ LiDAR depth sensing (ARKit)
- ✅ 3-zone obstacle detection (Left/Center/Right)
- ✅ Steering command logic
- ✅ Distance measurements in meters
- ✅ Haptic feedback (vibration pulses)
- ✅ BLE scanning (for ESP32 connection)
- ✅ Full SwiftUI interface

### Temporarily Disabled ⚠️
- ⚠️ Voice announcements (VoiceManager causes crash)
  - Can be tested later after investigating audio session conflicts
  - Not critical for core obstacle avoidance functionality

### Still Missing (Hardware Required) ❌
- ❌ BLE connection to ESP32 (shows "Disconnected" without hardware)
- ❌ Motor control testing (requires physical cane assembly)

---

## Testing the App (Without ESP32 Hardware)

### 1. Build and Run
```bash
# In Xcode
⌘R (or click Play button)
```

### 2. Grant Permissions
When app launches, grant permissions:
- **Camera** → Allow
- **Bluetooth** → Allow
- **Microphone** → Allow (even though voice is disabled)

### 3. Test LiDAR Obstacle Detection

**Step 1: Start System**
- Tap **"Start System"** button (turns red)
- LiDAR status turns **green** "LiDAR Active"

**Step 2: Point at Objects**
- Point iPhone at walls, furniture, objects
- Watch the distance values update:
  - **Left:** Distance to left side (in meters)
  - **Center:** Distance straight ahead
  - **Right:** Distance to right side

**Step 3: Observe Steering Commands**
The steering command will change based on obstacles:
- **"← LEFT"** → Obstacle on right, steer left
- **"→ NEUTRAL ←"** → Clear path, no steering
- **"RIGHT →"** → Obstacle on left, steer right

**Step 4: Feel Haptic Feedback**
- As you get closer to objects, vibration pulses get faster
- **Far (>1.5m):** No vibration
- **Medium (1.0-1.5m):** Slow pulses
- **Close (0.5-1.0m):** Medium pulses
- **Very Close (<0.5m):** Fast pulses

---

## Common Issues & Solutions

### Issue: "Developer Mode is not enabled"
**Solution:**
1. On iPhone: Settings → Privacy & Security → Developer Mode → ON
2. Restart iPhone
3. Try running again

### Issue: "No supported iOS devices available"
**Solution:**
Select an iOS Simulator from the device dropdown in Xcode toolbar.

### Issue: Simulator shows blank screen
**Cause:** Simulator doesn't have LiDAR hardware.
**Solution:** Use a physical iPhone 14 Pro (or newer) with LiDAR for full testing.

### Issue: Build succeeds but app crashes immediately
**Check:**
1. Xcode console for crash logs
2. Verify all privacy permissions are added to Info.plist
3. Check if initialization is completing (look for "[Controller] System initialized")

---

## Project File Structure (After Setup)

```
SmartCane/
├── SmartCane.xcodeproj/          # Xcode project (created fresh)
├── SmartCane/                     # Source code
│   ├── SmartCaneApp.swift        # App entry point
│   ├── ContentView.swift         # Main UI
│   ├── Core/
│   │   └── SmartCaneController.swift  # Main coordinator
│   ├── Sensors/
│   │   └── DepthSensor.swift     # ARKit + LiDAR
│   ├── Navigation/
│   │   ├── ObstacleDetector.swift
│   │   └── SteeringEngine.swift
│   ├── Communication/
│   │   └── BLEManager.swift      # Bluetooth
│   ├── Feedback/
│   │   ├── HapticManager.swift   # Vibration
│   │   └── VoiceManager.swift    # (Disabled)
│   └── Vision/
│       └── ObjectRecognizer.swift
```

---

## Next Steps

### To Re-enable Voice Manager
1. Investigate audio session configuration in `VoiceManager.swift`
2. Likely conflict with ARKit audio or app lifecycle
3. May need to delay voice initialization until after AR session starts

### To Connect ESP32 Hardware
1. Follow `QUICKSTART.md` Part 2 (ESP32 setup)
2. Upload firmware to ESP32
3. Power on ESP32
4. BLE status should change from red to green when connected

### To Add Camera Feed (Optional)
The attempt to add RealityKit ARView caused crashes. For camera preview:
- Use simpler `ARSCNView` instead of `ARView`
- Or use `AVCaptureVideoPreviewLayer`
- Not critical for functionality - obstacle detection works without camera view

---

## Summary of All Fixes

| # | Error | Fix |
|---|---|-----|
| 1 | Project won't open | Create new Xcode project, add source files manually |
| 2 | Multiple Info.plist | Remove Info.plist from Copy Bundle Resources build phase |
| 3 | Missing Combine import | Add `import Combine` to HapticManager, VoiceManager, ObjectRecognizer |
| 4 | Privacy crash | Add 5 privacy usage descriptions to Info.plist |
| 5 | Black screen (VoiceManager) | Disable VoiceManager initialization, add nil checks |

---

## Conclusion

The app is now **fully functional** for testing obstacle detection without ESP32 hardware. All core navigation features work:
- Real-time LiDAR depth sensing
- 3-zone obstacle analysis
- Intelligent steering decisions
- Distance-based haptic feedback

Voice announcements can be re-enabled later after resolving audio session conflicts.

---

**Last Updated:** February 14, 2026
**Status:** ✅ Core functionality working | ⚠️ Voice disabled | ❌ ESP32 not connected

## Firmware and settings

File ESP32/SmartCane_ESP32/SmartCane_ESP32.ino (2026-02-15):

#include <Arduino.h>
#include <NimBLEDevice.h>

static constexpr char kServiceUUID[] = "8A4E1E45-1E84-4AA2-B4B8-3D960D6CE001";
static constexpr char kDataCharacteristicUUID[] = "8A4E1E45-1E84-4AA2-B4B8-3D960D6CE002";

// Hardware pins from the standalone examples.
static constexpr int kTapticPin = 1;
static constexpr int kMotorForwardPin = 3;
static constexpr int kMotorReversePin = 2;

// Taptic pulse shape from the original Taptic.ino demo.
static constexpr uint32_t kCycleMicros = 3840;
static constexpr uint8_t kPulseCycles = 2;

// Motor behavior tuning (adjust on hardware).
static constexpr float kMotorInputScale = 1.0f / 255.0f;  // packet speed units -> normalized input
static constexpr float kMotorTauSeconds = 0.55f;           // slightly faster exponential decay time constant
static constexpr uint32_t kPacketTimeoutMs = 250;          // if packets stop arriving, force speed input to zero

portMUX_TYPE gDataMux = portMUX_INITIALIZER_UNLOCKED;
volatile float gSpeedField = 0.0f;     // packet field #1 (called angle in iOS UI)
volatile float gDistanceField = 0.0f;  // packet field #2
volatile uint32_t gModeField = 0;      // packet field #3
volatile uint32_t gLastPacketMs = 0;

void doTapticPulse() {
  for (uint8_t i = 0; i < kPulseCycles; ++i) {
    digitalWrite(kTapticPin, HIGH);
    delayMicroseconds(kCycleMicros);
    digitalWrite(kTapticPin, LOW);
    delayMicroseconds(kCycleMicros);
  }
}


uint8_t capPwm255(float pwmValue) {
  const float capped = constrain(pwmValue, 0.0f, 255.0f);
  return static_cast<uint8_t>(roundf(capped));
}

float distanceToPulseIntervalMs(float distanceValue) {
  const float d = constrain(distanceValue, 0.0f, 500.0f);
  constexpr float minIntervalMs = 60.0f;    // very frequent at near distance
  constexpr float maxIntervalMs = 3000.0f;  // infrequent at far distance
  return minIntervalMs + (d / 500.0f) * (maxIntervalMs - minIntervalMs);
}

class DataCallbacks : public NimBLECharacteristicCallbacks {
  void onWrite(NimBLECharacteristic* pCharacteristic, NimBLEConnInfo& connInfo) override {
    (void)connInfo;
    std::string value = pCharacteristic->getValue();

    if (value.size() != 12) {
      Serial.printf("RX size %d (expected 12)\n", static_cast<int>(value.size()));
      return;
    }

    float speed = 0.0f;
    float distance = 0.0f;
    uint32_t mode = 0;

    memcpy(&speed, value.data(), 4);
    memcpy(&distance, value.data() + 4, 4);
    memcpy(&mode, value.data() + 8, 4);

    portENTER_CRITICAL(&gDataMux);
    gSpeedField = speed;
    gDistanceField = distance;
    gModeField = mode;
    gLastPacketMs = millis();
    portEXIT_CRITICAL(&gDataMux);

    Serial.printf("Speed(field1): %.2f | Distance: %.2f | Mode: %lu\n",
                  speed,
                  distance,
                  static_cast<unsigned long>(mode));
  }
};

class ServerCallbacks : public NimBLEServerCallbacks {
  void onConnect(NimBLEServer* server, NimBLEConnInfo& connInfo) override {
    (void)server;
    (void)connInfo;
    Serial.println("BLE connected");
  }

  void onDisconnect(NimBLEServer* server, NimBLEConnInfo& connInfo, int reason) override {
    (void)connInfo;
    Serial.printf("BLE disconnected (reason %d), restarting advertising\n", reason);

    portENTER_CRITICAL(&gDataMux);
    gSpeedField = 0.0f;
    gLastPacketMs = 0;
    portEXIT_CRITICAL(&gDataMux);

    server->startAdvertising();
  }
};

void tapticTask(void* parameter) {
  (void)parameter;
  uint32_t lastPulseMs = millis();

  while (true) {
    float distanceSnapshot = 0.0f;
    portENTER_CRITICAL(&gDataMux);
    distanceSnapshot = gDistanceField;
    portEXIT_CRITICAL(&gDataMux);

    const float intervalMs = distanceToPulseIntervalMs(distanceSnapshot);
    const uint32_t now = millis();
    if (now - lastPulseMs >= static_cast<uint32_t>(intervalMs)) {
      doTapticPulse();
      lastPulseMs = millis();
    }

    vTaskDelay(pdMS_TO_TICKS(5));
  }
}

void motorTask(void* parameter) {
  (void)parameter;
  float motorState = 0.0f;  // Stored "impulse"/energy state
  uint32_t lastMs = millis();

  while (true) {
    const uint32_t nowMs = millis();
    float dt = (nowMs - lastMs) / 1000.0f;
    if (dt <= 0.0f) {
      dt = 0.001f;
    }
    lastMs = nowMs;

    float speedInput = 0.0f;
    uint32_t lastPacketMs = 0;
    portENTER_CRITICAL(&gDataMux);
    speedInput = gSpeedField;
    lastPacketMs = gLastPacketMs;
    portEXIT_CRITICAL(&gDataMux);

    if (lastPacketMs == 0 || (nowMs - lastPacketMs) > kPacketTimeoutMs) {
      speedInput = 0.0f;
    }

    // Signed leaky integrator: dS/dt = input - S/tau
    // Positive integral drives forward, negative integral drives reverse.
    // Output is S/tau, so integrated output tracks integrated input when S starts/ends near zero.
    const float inputNorm = constrain(speedInput * kMotorInputScale, -1.0f, 1.0f);
    motorState += dt * (inputNorm - (motorState / kMotorTauSeconds));

    const float outputNorm = constrain(motorState / kMotorTauSeconds, -1.0f, 1.0f);
    const uint8_t pwm = capPwm255(fabsf(outputNorm) * 255.0f);

    if (outputNorm >= 0.0f) {
      analogWrite(kMotorReversePin, 0);
      analogWrite(kMotorForwardPin, pwm);
    } else {
      analogWrite(kMotorForwardPin, 0);
      analogWrite(kMotorReversePin, pwm);
    }

    vTaskDelay(pdMS_TO_TICKS(20));
  }
}

NimBLECharacteristic* dataCharacteristic = nullptr;

void setup() {
  Serial.begin(115200);
  delay(1000);

  pinMode(kTapticPin, OUTPUT);
  pinMode(kMotorForwardPin, OUTPUT);
  pinMode(kMotorReversePin, OUTPUT);
  analogWrite(kMotorForwardPin, 0);
  analogWrite(kMotorReversePin, 0);

  NimBLEDevice::init("ESP32-S3-BLE");
  NimBLEDevice::setPower(ESP_PWR_LVL_P9);

  NimBLEServer* server = NimBLEDevice::createServer();
  server->setCallbacks(new ServerCallbacks());
  NimBLEService* service = server->createService(kServiceUUID);

  dataCharacteristic = service->createCharacteristic(
      kDataCharacteristicUUID,
      NIMBLE_PROPERTY::WRITE | NIMBLE_PROPERTY::WRITE_NR
  );
  dataCharacteristic->setCallbacks(new DataCallbacks());

  service->start();

  NimBLEAdvertising* advertising = NimBLEDevice::getAdvertising();
  advertising->addServiceUUID(kServiceUUID);
  advertising->setName("ESP32-S3-BLE");
  advertising->start();

  xTaskCreatePinnedToCore(tapticTask, "tapticTask", 4096, nullptr, 1, nullptr, 1);
  xTaskCreatePinnedToCore(motorTask, "motorTask", 4096, nullptr, 1, nullptr, 1);

  Serial.println("BLE ready. Waiting for iOS app writes...");
}

void loop() {
  // BLE + workers run continuously; keep loop idle.
  vTaskDelay(pdMS_TO_TICKS(100));
}

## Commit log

2026-02-14 working swift setup, basic lidar seems to work. voice_manager disabled for now bcz voice_manager keeps crashing the app
2026-02-14 lidar depth map added
2026-02-14 ui improvements, camera overlay added
2026-02-14 good. now just need to work on steering logic, refine that
2026-02-14 lidar works good horizontally; next fixes are make it decide faster (i.e. from further out), and also maybe use some object detection logic to help move in the algo (e.g. if there is a person detecte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
2026-02-14 integrate Vapi voice assistant for spoken navigation guidance
    - Add VapiManager.swift wrapping Vapi iOS SDK (start/stop/mute, controlUrl sensor injection, urgent alerts)
    - Integrate into SmartCaneController pipeline with throttled sensor summaries every 5s
    - Critical obstacles (<0.6m) trigger immediate spoken "Stop" alert via controlUrl
    - Add Voice Assistant UI section in ContentView (call controls, mute, transcript, status)
    - Update Info.plist with voip + audio background modes for Vapi
2026-02-15 Add continuous zone weighting, faster person detection, and wall/ahead evasion
    - Person detection throttle reduced from 5s to 0.5s (~2Hz) for responsive feedback
    - Steering changed from discrete Int8 (-1/0/+1) to continuous Float (-1.0 to +1.0)
    - ObstacleZones extended with lateralBias, averageLeftDistance, averageRightDistance
    - SteeringEngine rewritten: center obstacle <1m forces non-zero steering, wall
    detection uses average distances as tie-breaker, critical <0.6m forces max intensity
    - UI arrows scale proportionally to steering magnitude, dot offset uses full range
    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
2026-02-15 Add EMA temporal smoothing to fix hallway steering oscillation
    Applies exponential moving average (alpha=0.2) as post-processing in
    SteeringEngine to eliminate LEFT/RIGHT ping-ponging in hallways.
    Safety-critical commands (confidence 1.0 + max magnitude) bypass
    smoothing for instant reaction. Resets smoother state on system stop.
2026-02-15 Add frame watchdog to zero steering when depth pipeline stalls
    Starts a 250ms repeating timer when the system activates. If no depth
    frame arrives for 500ms, the watchdog zeroes steering, motor output,
    and haptics as a safe fallback. Timer is cleaned up on system stop.
2026-02-15 Implement weighted temporal tiebreaker with EMA smoothing
    Add exponentially-weighted moving average (EMA) history of zone data
    inside SteeringEngine to stabilize tiebreaking in symmetric environments
    (hallways, doorways) where per-frame data can flicker.
    Changes:
    - SteeringEngine: Add temporal EMA state (emaLeftDist, emaRightDist,
    emaLateralBias) with configurable alpha (default 0.08 = ~2-3s memory)
    - Replace instantaneous zone lookups in both tiebreaker paths with EMA
    values for stable direction selection
    - Add SteeringTuning struct to parameterize temporalAlpha, smoothingAlpha,
    centerDeadband, lateralDeadband
    - Extend reset() to clear EMA state on system toggle
    - SmartCaneController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
2026-02-15 Real ESP32 Code
2026-02-15 Remove dead BLEManager (1-byte protocol) — ESP32 only accepts 12-byte packets
    BLEManager used UUIDs and a 1-byte protocol that don't match the real ESP32
    firmware. The actual hardware expects 12-byte packets on 8A4E1E45 UUIDs,
    which ESPBluetoothManager already sends correctly. Removes all BLEManager
    references and rewires isConnected to ESPBluetoothManager's connectedName.
    [SmartCane_ESP32.ino]
2026-02-15 Fix motor output scaling and add live tuning sliders
    ESP32 divides field 1 by 255 to normalize — we were sending ±2 (PWM ≈ 1).
    Now sends command × motorBaseScale(113) × magnitude(1.0) for real motor output.
    Steering improvements:
    - Cube root gap boost + pow(prox, exponent) for faster ramp
    - 5-frame running average on gapDirection to stabilize depth noise
    - Minimum command floor when obstacle < 1m
    New live-adjustable sliders on Bluetooth debug page:
    - Motor Base Scale (10-255): raw speed ceiling
    - Magnitude (0.1-3.0): extra multiplier
    - Proximity Exponent (0.2-1.5): urgency ramp curve
    - Close Floor (0-1.0): minimum command near obstacles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
2026-02-15 Add Nintendo Switch Joy-Con steering override
    Team member can override autonomous steering with a Joy-Con paired via
    iOS Settings. Left stick X axis controls direction; releasing the stick
    returns to autonomous mode. Uses Apple's GCController framework.
    - Create GameControllerManager (listens for controller, reads stick input)
    - Override steering in updateESPMotor when joystick is active
    - Skip frame watchdog zeroing during manual override
2026-02-15 Add GPS pedestrian navigation with route map and accessibility routing
    Two-layer navigation: GPS handles macro route guidance (turns, crosswalks,
    signals) via Google Routes API + Overpass API, while existing LiDAR pipeline
    continues micro obstacle avoidance independently.
    New files:
    - WaypointModels.swift: Route, step, maneuver, infrastructure data types
    - RouteService.swift: Google Geocoding + Routes API + Overpass infrastructure
    - NavigationManager.swift: CLLocationManager state machine with step advancement
    - NavigationView.swift: Destination input sheet + navigation HUD overlay
    - RouteMapView.swift: MapKit route visualization with waypoints and infrastructure
    Accessibility: avoidIndoor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
2026-02-15 Switch pedestrian routing to OpenRouteService wheelchair profile
    Replace Google Routes API with ORS wheelchair endpoint to avoid stairs
    and other inaccessible features. Google still used for geocoding.
2026-02-15 Add navigation compass and micro-waypoint map overlay
    Rotating compass dial shows fused heading, waypoint bearing, heading
    error arc, and nav bias during active navigation. Micro-waypoint dots
    overlay on the route map with a toggle button. NavigationSteering
    provides the heading fusion, waypoint tracking, and bias computation.
2026-02-15 Add Joy-Con kill button and fix controls
    - Any button = emergency motor stop (hold to kill, release to resume)
    - Uses physicalInputProfile to detect all available buttons
    - Increase joystick override force to 2.5x (200/255 max PWM)
    - Fix stick axis: Y axis for sideways Joy-Con (physical left/right)
2026-02-15 Add hardware assembly instructions, 3D print files, and CAD images
    Includes a beginner-friendly BOM, step-by-step assembly guide,
    wiring pinout table, and all STL files for the smart cane build.
    [handle - electronics cover.stl, handle - handle cover (1).stl, motor mounting - motor clamp (4).stl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]
2026-02-15 Rewrite README as a project landing page
    Replace internal development notes with a public-facing README that
    explains the problem, our approach, technical architecture, hardware
    design, and step-by-step build/run instructions for the iOS app and
    ESP32 firmware.
2026-02-15 Remove HARDWARE_SETUP.md, now covered by Hardware/Assembly Instructions.md
    Update references in QUICKSTART.md to point to the new assembly guide.
